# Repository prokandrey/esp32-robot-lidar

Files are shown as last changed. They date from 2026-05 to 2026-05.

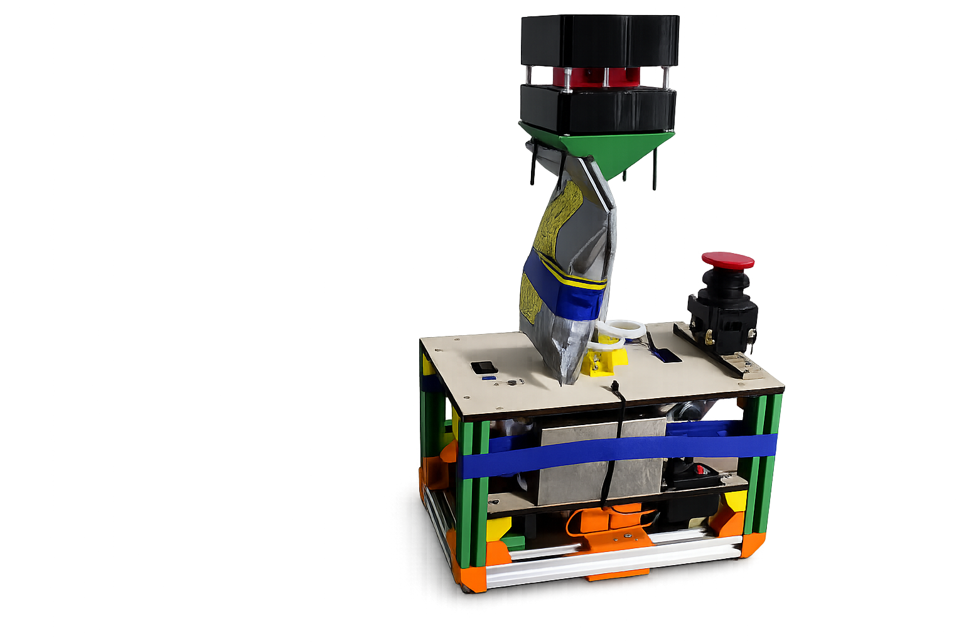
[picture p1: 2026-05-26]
ChatGPT Image 15 мая 2026 г., 21_02_37.png

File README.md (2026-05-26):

# ESP32 - Подключение компонентов

## Полная таблица пинов ESP32

| Компонент | Сигнал | Пин ESP32 |
|---|---|---|
| **A4988 #1 (левый двигатель)** | STEP | GPIO19 |
| | DIR | GPIO18 |
| | ENABLE | GPIO17 |
| **A4988 #2 (правый двигатель)** | STEP | GPIO23 |
| | DIR | GPIO22 |
| | ENABLE | GPIO21 |
| **Лидар** | TX (на вход ESP32) | GPIO16 |
| **Кнопка ROUTE** | INPUT_PULLUP | GPIO26 |
| **Кнопка START** | INPUT_PULLUP | GPIO27 |
| **Серво 0** | PWM | GPIO33 |
| **Серво 1** | PWM | GPIO25 |

## Подключение драйвера A4988

| Пин A4988 | Куда подключать |
|---|---|
| STEP | GPIO19 (мотор 1) / GPIO23 (мотор 2) |
| DIR | GPIO18 (мотор 1) / GPIO22 (мотор 2) |
| EN | GPIO17 (мотор 1) / GPIO21 (мотор 2) |
| VDD | 3.3V ESP32 |
| VMOT | 12-24V внешний БП |
| GND | GND ESP32 + GND внешнего БП |
| MS1 | GND |
| MS2 | 3.3V |
| MS3 | GND |

## Подключение лидара

| Лидар | ESP32 |
|---|---|
| TX | GPIO16 |
| VCC | 5V |
| GND | GND |

## Подключение кнопок

| Кнопка | ESP32 | Примечание |
|---|---|---|
| ROUTE | GPIO26 | INPUT_PULLUP, активен LOW |
| START | GPIO27 | INPUT_PULLUP, активен LOW |

## Подключение сервоприводов

| Серво | ESP32 | Питание |
|---|---|---|
| Серво 0 | GPIO33 | 5V |
| Серво 1 | GPIO25 | 5V |

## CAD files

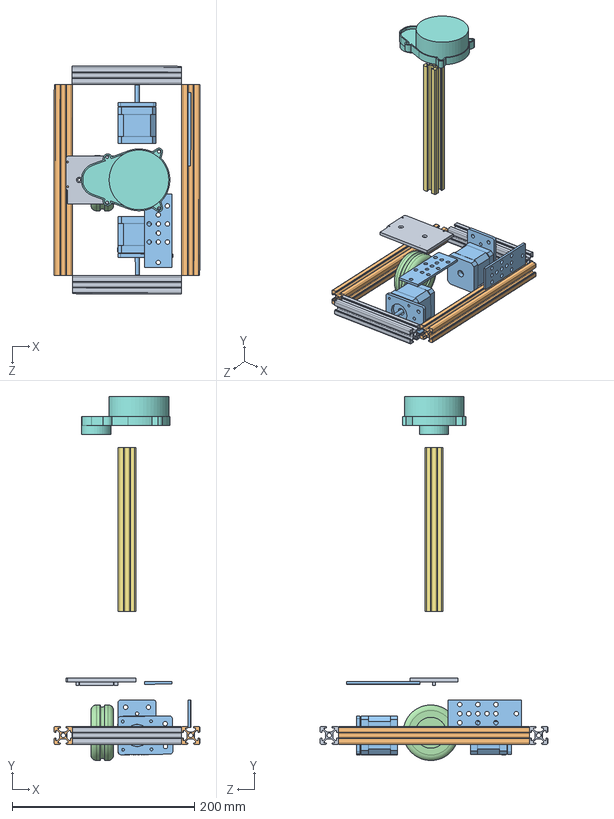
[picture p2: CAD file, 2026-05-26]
Сборка2.SLDASM
160.2 x 399.8 x 250.1 mm
Profile_2020 — 160 x 2
Profile_2020 —250 x 2
nema17 x 2
OmniWheel
баклаха x 2
фигаподшифник
Profile_2020 —250 — копия
ydlidar x4
подставкадляесп

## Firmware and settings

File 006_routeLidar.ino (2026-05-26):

#include <Arduino.h>
#include <GyverStepper.h>
#include <ESP32Servo.h>

// ===================== ПИНЫ =====================

const int ROUTE_PIN = 26;
const int START_PIN = 27;

// Лидар
#define LIDAR_RX_PIN 16
#define LIDAR_TX_PIN -1
#define LIDAR_BAUDRATE 115200

// До 6 серв
#define SERVO_UNUSED -1

const int SERVO_PINS[6] = {
  33,            // servo 0
  25,            // servo 1
  SERVO_UNUSED,  // servo 2
  SERVO_UNUSED,  // servo 3
  SERVO_UNUSED,  // servo 4
  SERVO_UNUSED   // servo 5
};

const int SERVO_COUNT = 6;

// Шаговые двигатели
GStepper<STEPPER2WIRE> stepper1(800, 19, 18, 17);
GStepper<STEPPER2WIRE> stepper2(800, 23, 22, 21);

// Сервы
Servo servos[SERVO_COUNT];

// ===================== СЕКТОРА ЛИДАРА =====================

#define NUM_SECTORS 12

#define SEC(n) (1 << (n))

#define SECTORS_NONE 0
#define SECTORS_ALL  0x0FFF

#define SECTORS_FRONT (SEC(7) | SEC(8) | SEC(9) | SEC(10) | SEC(11) | SEC(0))
#define SECTORS_BACK  (SEC(1) | SEC(2) | SEC(3) | SEC(4) | SEC(5) | SEC(6))

int sectorStatus[NUM_SECTORS] = { 0 };

// ===================== ПАРАМЕТРЫ ЛИДАРА =====================

static const uint8_t LIDAR_HEADER[] = { 0x55, 0xAA, 0x03, 0x08 };
static const uint8_t LIDAR_HEADER_LEN = 4;
static const uint8_t LIDAR_BODY_LEN = 32;

#define ALARM_DIST 250
#define WARNING_DIST 300
#define ALARM_HOLD_MS 300
#define SECTOR_OFFSET 1

static float sectorDistances[NUM_SECTORS] = { 0.0f };
static uint32_t sectorUpdateTime[NUM_SECTORS] = { 0 };
static uint32_t sectorAlarmUntil[NUM_SECTORS] = { 0 };

static const float NO_VALUE = 99999.0f;

// ===================== ТИПЫ ШАГОВ =====================

enum StepType {
  MOVE_STEPPERS,
  SERVO_MOVE,
  PAUSE_STEP,
  END_ROUTE
};

struct RouteStep {
  StepType type;

  long motor1Steps;
  long motor2Steps;

  int servoIndex;
  int servoAngle;

  unsigned long timeMs;

  uint16_t checkSectors;
};

// ===================== МАРШРУТЫ =====================
//
// Формат:
// {ТИП, motor1, motor2, servoIndex, servoAngle, timeMs, checkSectors}

RouteStep route1[] = {
  {MOVE_STEPPERS, 15000, 15000, -1,  0,    0, SECTORS_FRONT},
  {MOVE_STEPPERS, -600, -600, -1,  0,    0, SECTORS_BACK},
  {MOVE_STEPPERS, 1500, -1500, -1,  0,    0, SECTORS_ALL},
  {MOVE_STEPPERS, 2700, 2700, -1,  0,    0, SECTORS_FRONT},
  {MOVE_STEPPERS, 1500, -1500, -1,  0,    0, SECTORS_ALL},
  {MOVE_STEPPERS, -1000, -1000, -1,  0,    0, SECTORS_BACK},
  {MOVE_STEPPERS, 14000, 14000, -1,  0,    0, SECTORS_FRONT},
  {MOVE_STEPPERS, -13100, -13100, -1,  0,    0, SECTORS_BACK},
  {MOVE_STEPPERS, -1500, 1500, -1,  0,    0, SECTORS_ALL},
  {MOVE_STEPPERS, 2000, 2000, -1,  0,    0, SECTORS_FRONT},
  {SERVO_MOVE,    0,    0,     1,  0,  500, SECTORS_ALL},
  {MOVE_STEPPERS, -5100, -5100, -1,  0,    0, SECTORS_BACK},
  {SERVO_MOVE,    0,    0,     1, 43,  500, SECTORS_ALL},
  {MOVE_STEPPERS, 1900, 1900,  -1,  0,    0, SECTORS_FRONT},
  {MOVE_STEPPERS, 1500, -1500, -1,  0,    0, SECTORS_ALL},
  {MOVE_STEPPERS, -1500, -1500, -1,  0,    0, SECTORS_BACK},
  {MOVE_STEPPERS, 15000, 15000, -1,  0,    0, SECTORS_FRONT},
  {END_ROUTE,     0,    0,    -1,  0,    0, SECTORS_NONE}
};

// ИЗМЕНЁННЫЙ route2 – зеркальный к route1
RouteStep route2[] = {
  {MOVE_STEPPERS, 15000, 15000, -1,  0,    0, SECTORS_FRONT},
  {MOVE_STEPPERS, -650, -650, -1,  0,    0, SECTORS_BACK},
  {MOVE_STEPPERS, -1500, 1500, -1,  0,    0, SECTORS_ALL},
  {MOVE_STEPPERS, 2600, 2600, -1,  0,    0, SECTORS_FRONT},
  {MOVE_STEPPERS, -1500, 1500, -1,  0,    0, SECTORS_ALL},
  {MOVE_STEPPERS, -1000, -1000, -1,  0,    0, SECTORS_BACK},
  {MOVE_STEPPERS, 14000, 14000, -1,  0,    0, SECTORS_FRONT},
  {MOVE_STEPPERS, -13100, -13100, -1,  0,    0, SECTORS_BACK},
  {MOVE_STEPPERS, 1500, -1500, -1,  0,    0, SECTORS_ALL},
  {MOVE_STEPPERS, 2000, 2000, -1,  0,    0, SECTORS_FRONT},
  {SERVO_MOVE,    0,    0,     0,  0,  500, SECTORS_ALL},
  {MOVE_STEPPERS, -5100, -5100, -1,  0,    0, SECTORS_BACK},
  {SERVO_MOVE,    0,    0,     0, 40,  500, SECTORS_ALL},
  {MOVE_STEPPERS, 2250, 2250,  -1,  0,    0, SECTORS_FRONT},
  {MOVE_STEPPERS, -1500, 1500, -1,  0,    0, SECTORS_ALL},
  {MOVE_STEPPERS, -1500, -1500, -1,  0,    0, SECTORS_BACK},
  {MOVE_STEPPERS, 15000, 15000, -1,  0,    0, SECTORS_FRONT},
  {END_ROUTE,     0,    0,    -1,  0,    0, SECTORS_NONE}
};

// ===================== ПЕРЕМЕННЫЕ МАРШРУТА =====================

RouteStep* currentRoute;

int currentStepIndex = 0;

bool stepStarted = false;
bool motorsWereMoving = false;

unsigned long stepStartTime = 0;

int activeServoIndex = -1;

// ===================== ЛИДАР =====================

bool readBytesWithTimeout(HardwareSerial &ser, uint8_t *buffer, size_t length, uint32_t timeout_ms = 2) {
  uint32_t start = millis();
  size_t count = 0;

  while (count < length) {
    if (ser.available()) {
      buffer[count++] = ser.read();
    }

    if (millis() - start > timeout_ms) {
      return false;
    }
  }

  return true;
}

bool waitForHeader(HardwareSerial &ser) {
  uint8_t matchPos = 0;
  uint32_t start = millis();

  while (millis() - start < 1) {
    if (ser.available()) {
      uint8_t b = ser.read();

      if (b == LIDAR_HEADER[matchPos]) {
        matchPos++;

        if (matchPos == LIDAR_HEADER_LEN) {
          return true;
        }
      } else {
        matchPos = 0;
      }
    }
  }

  return false;
}

float decodeAngle(uint16_t rawAngle) {
  float angleDeg = (float)(rawAngle - 0xA000) / 64.0f;

  while (angleDeg < 0) angleDeg += 360.0f;
  while (angleDeg >= 360) angleDeg -= 360.0f;

  return angleDeg;
}

int angleToSector(float angleDeg) {
  float shifted = angleDeg + 15.0f;

  while (shifted < 0) shifted += 360.0f;
  while (shifted >= 360) shifted -= 360.0f;

  int sector = (int)(shifted / 30.0f) % NUM_SECTORS;
  sector = (sector + SECTOR_OFFSET) % NUM_SECTORS;

  return sector;
}

void updateSectorStatuses() {
  uint32_t now = millis();

  for (int s = 0; s < NUM_SECTORS; s++) {
    float dist = sectorDistances[s];

    if (dist == NO_VALUE) {
      sectorStatus[s] = 0;
    } else if (now < sectorAlarmUntil[s]) {
      sectorStatus[s] = 2;
    } else if (dist < WARNING_DIST) {
      sectorStatus[s] = 1;
    } else {
      sectorStatus[s] = 0;
    }
  }
}

bool parseAndProcessLidarPacket() {
  if (!waitForHeader(Serial1)) {
    updateSectorStatuses();
    return false;
  }

  uint8_t buffer[LIDAR_BODY_LEN];

  if (!readBytesWithTimeout(Serial1, buffer, LIDAR_BODY_LEN, 2)) {
    updateSectorStatuses();
    return false;
  }

  uint16_t startAngleTmp = buffer[2] | (buffer[3] << 8);
  float startAngleDeg = decodeAngle(startAngleTmp);

  uint8_t offset = 4;

  uint16_t distances[8];
  uint8_t intensities[8];

  for (int i = 0; i < 8; i++) {
    distances[i] = buffer[offset] | (buffer[offset + 1] << 8);
    intensities[i] = buffer[offset + 2];
    offset += 3;
  }

  uint16_t endAngleTmp = buffer[offset] | (buffer[offset + 1] << 8);
  float endAngleDeg = decodeAngle(endAngleTmp);

  if (endAngleDeg < startAngleDeg) {
    endAngleDeg += 360.0f;
  }

  float angleRange = endAngleDeg - startAngleDeg;
  float angleInc = angleRange / 8.0f;

  float tempSectorMin[NUM_SECTORS];

  for (int s = 0; s < NUM_SECTORS; s++) {
    tempSectorMin[s] = NO_VALUE;
  }

  for (int i = 0; i < 8; i++) {
    if (intensities[i] > 15) {
      float angle = startAngleDeg + i * angleInc;

      while (angle < 0) angle += 360.0f;
      while (angle >= 360) angle -= 360.0f;

      int sectorIndex = angleToSector(angle);
      float dist = (float)distances[i];

      if (dist < tempSectorMin[sectorIndex]) {
        tempSectorMin[sectorIndex] = dist;
      }
    }
  }

  uint32_t now = millis();

  for (int s = 0; s < NUM_SECTORS; s++) {
    if (tempSectorMin[s] != NO_VALUE) {
      sectorDistances[s] = tempSectorMin[s];
      sectorUpdateTime[s] = now;
    }
  }

  for (int s = 0; s < NUM_SECTORS; s++) {
    if ((now - sectorUpdateTime[s]) > 500) {
      sectorDistances[s] = NO_VALUE;
    }
  }

  for (int s = 0; s < NUM_SECTORS; s++) {
    float dist = sectorDistances[s];

    if (dist < ALARM_DIST && dist>130) {
      sectorAlarmUntil[s] = now + ALARM_HOLD_MS;
    }
  }

  updateSectorStatuses();
  return true;
}

bool isBlockedByLidar(uint16_t checkSectors) {
  if (checkSectors == SECTORS_NONE) {
    return false;
  }

  for (int s = 0; s < NUM_SECTORS; s++) {
    if (checkSectors & SEC(s)) {
      if (sectorStatus[s] == 2) {
        return true;
      }
    }
  }

  return false;
}

void printSectorStatuses() {
  Serial.print("SECTORS: ");

  for (int s = 0; s < NUM_SECTORS; s++) {
    Serial.print(sectorStatus[s]);

    if (s < NUM_SECTORS - 1) {
      Serial.print(",");
    }
  }

  Serial.println();
}

// ===================== МОТОРЫ =====================

void setupSteppers() {
  stepper1.setRunMode(FOLLOW_POS);
  stepper2.setRunMode(FOLLOW_POS);

  stepper1.setMaxSpeed(2000);
  stepper1.setAcceleration(3000);

  stepper2.setMaxSpeed(2000);
  stepper2.setAcceleration(3000);

  stepper1.autoPower(true);
  stepper2.autoPower(true);

  stepper1.enable();
  stepper2.enable();
}

// ===================== СЕРВЫ =====================

bool isServoAvailable(int index) {
  if (index < 0 || index >= SERVO_COUNT) return false;
  if (SERVO_PINS[index] == SERVO_UNUSED) return false;
  return true;
}

void attachAndWriteServo(int index, int angle) {
  if (!isServoAvailable(index)) {
    Serial.print("SERVO ");
    Serial.print(index);
    Serial.println(" is unused. Skip.");
    return;
  }

  angle = constrain(angle, 0, 180);

  servos[index].attach(SERVO_PINS[index], 500, 2500);
  servos[index].write(angle);

  activeServoIndex = index;

  Serial.print("SERVO ");
  Serial.print(index);
  Serial.print(" on pin ");
  Serial.print(SERVO_PINS[index]);
  Serial.print(" -> ");
  Serial.println(angle);
}

void detachActiveServo() {
  if (isServoAvailable(activeServoIndex)) {
    servos[activeServoIndex].detach();

    Serial.print("SERVO ");
    Serial.print(activeServoIndex);
    Serial.println(" DETACH");
  }

  activeServoIndex = -1;
}

// ===================== ЗАПУСК ШАГА =====================

void startRouteStep(RouteStep step) {
  stepStartTime = millis();

  if (step.type == MOVE_STEPPERS) {
    motorsWereMoving = false;

    Serial.print("MOVE: ");
    Serial.print(step.motor1Steps);
    Serial.print(" / ");
    Serial.println(step.motor2Steps);

    stepper1.setTarget(step.motor1Steps, RELATIVE);
    stepper2.setTarget(step.motor2Steps, RELATIVE);
  }

  else if (step.type == SERVO_MOVE) {
    attachAndWriteServo(step.servoIndex, step.servoAngle);
  }

  else if (step.type == PAUSE_STEP) {
    Serial.print("PAUSE: ");
    Serial.print(step.timeMs);
    Serial.println(" ms");
  }

  stepStarted = true;
}

// ===================== ПРОВЕРКА ЗАВЕРШЕНИЯ ШАГА =====================

bool isRouteStepFinished(RouteStep step, byte stepper1Move, byte stepper2Move) {
  if (step.type == MOVE_STEPPERS) {
    if (stepper1Move != 0 || stepper2Move != 0) {
      motorsWereMoving = true;
    }

    return motorsWereMoving && stepper1Move == 0 && stepper2Move == 0;
  }

  if (step.type == SERVO_MOVE) {
    if (millis() - stepStartTime >= step.timeMs) {
      detachActiveServo();
      return true;
    }

    return false;
  }

  if (step.type == PAUSE_STEP) {
    return millis() - stepStartTime >= step.timeMs;
  }

  return false;
}

// ===================== SETUP =====================

void setup() {
  Serial.begin(115200);

  pinMode(ROUTE_PIN, INPUT_PULLUP);
  pinMode(START_PIN, INPUT_PULLUP);

  Serial1.begin(LIDAR_BAUDRATE, SERIAL_8N1, LIDAR_RX_PIN, LIDAR_TX_PIN);

  setupSteppers();

  Serial.println("Robot route program with lidar safety");

  Serial.println("Servo configuration:");
  for (int i = 0; i < SERVO_COUNT; i++) {
    Serial.print("Servo ");
    Serial.print(i);
    Serial.print(": ");

    if (SERVO_PINS[i] == SERVO_UNUSED) {
      Serial.println("UNUSED");
    } else {
      Serial.print("GPIO ");
      Serial.println(SERVO_PINS[i]);
    }
  }

  if (digitalRead(ROUTE_PIN) == LOW) {
    currentRoute = route2;
    Serial.println("Selected route: 2 (mirrored)");
  } else {
    currentRoute = route1;
    Serial.println("Selected route: 1");
  }

  Serial.println("Waiting START_PIN press...");

  while (digitalRead(START_PIN) == HIGH) {
    parseAndProcessLidarPacket();
    delay(1);
  }

  Serial.println("START!");
}

// ===================== LOOP (исправленный, с защитой, без рывков) =====================

void loop() {
  RouteStep currentStep = currentRoute[currentStepIndex];

  if (currentStep.type == END_ROUTE) {
    Serial.println("ROUTE FINISHED");

    while (true) {
      parseAndProcessLidarPacket();
      delay(10);
    }
  }

  bool blocked = isBlockedByLidar(currentStep.checkSectors);

  static bool wasBlocked = false;
  static long remaining1 = 0;
  static long remaining2 = 0;

  if (blocked && !wasBlocked) {
    // Вычисляем оставшиеся шаги (сколько ещё нужно проехать)
    remaining1 = stepper1.getTarget() - stepper1.getCurrent();
    remaining2 = stepper2.getTarget() - stepper2.getCurrent();
    // Останавливаем моторы
    stepper1.setTarget(0, RELATIVE);
    stepper2.setTarget(0, RELATIVE);
    Serial.println("LIDAR BLOCKED - motors stopped");
    wasBlocked = true;
  }
  else if (!blocked && wasBlocked) {
    // Возобновляем движение с оставшимися шагами
    if (remaining1 != 0) stepper1.setTarget(remaining1, RELATIVE);
    if (remaining2 != 0) stepper2.setTarget(remaining2, RELATIVE);
    motorsWereMoving = false;
    Serial.println("LIDAR CLEAR - resuming");
    wasBlocked = false;
  }

  // ВСЕГДА вызываем tick() – это устраняет рывки
  byte stepper1Move = stepper1.tick();
  byte stepper2Move = stepper2.tick();

  parseAndProcessLidarPacket();

  if (blocked) {
    delay(1);
    return;
  }

  if (!stepStarted) {
    startRouteStep(currentStep);
  }

  if (isRouteStepFinished(currentStep, stepper1Move, stepper2Move)) {
    Serial.print("Step finished: ");
    Serial.println(currentStepIndex);

    currentStepIndex++;
    stepStarted = false;
    motorsWereMoving = false;
    remaining1 = remaining2 = 0;
    delay(10);
  }
}
